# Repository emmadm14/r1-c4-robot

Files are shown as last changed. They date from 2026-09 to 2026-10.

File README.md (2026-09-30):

# R1-C4 – Experimental Assistant Robot

<p align="center">
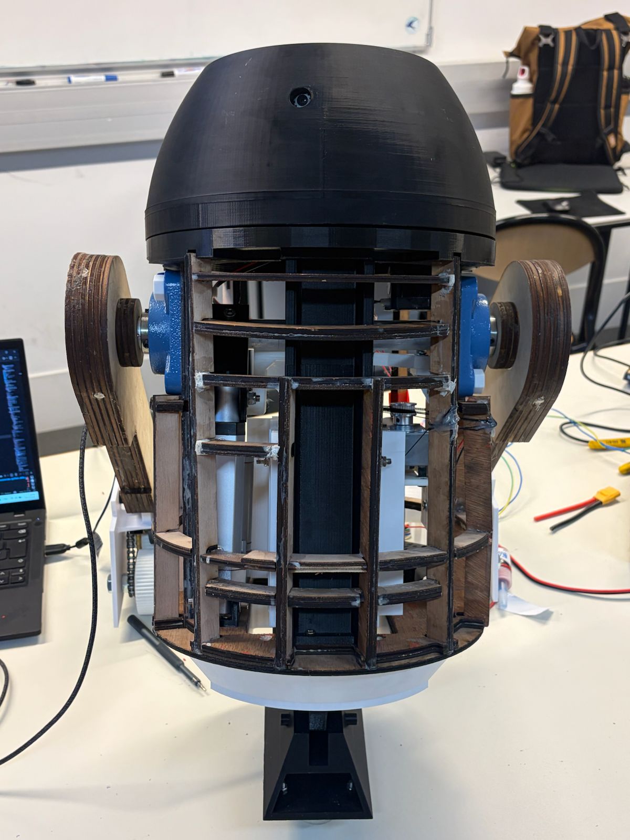
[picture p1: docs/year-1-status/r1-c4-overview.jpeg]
R1-C4 robot prototype
  
</p>

R1-C4 is an experimental assistant robot project inspired by the R2-D2 universe and developed at **Polytech Nice Sophia** as part of the **Experimental Robotics** course.

The project can be developed throughout the three years of the engineering cycle. I am currently in the **second year of development** of R1-C4.

The objective is to progressively design, prototype and improve a functional assistant robot at approximately **3/5 scale**, combining mechanical design, embedded systems, 3D printing, electronics, actuation and autonomous functions.

---

## Contents

- [Project Context](#project-context)
- [Project Objectives](#project-objectives)
- [Development History](#development-history)
- [Main Subsystems](#main-subsystems)
- [Design and Manufacturing](#design-and-manufacturing)
- [Documentation](#documentation)
- [Project Structure](#project-structure)
- [Technologies](#technologies)
- [Current Development](#current-development)
- [Authorship and Credits](#authorship-and-credits)

---

## Project Context

R1-C4 was started during my **3rd year of engineering studies** at Polytech Nice Sophia.

During the first development year, I worked on the project together with **Vladimir Grigoriev**.

My work focused mainly on:

- The **2-3-2 transformation system**
- The **central-foot lift**
- Mechanical integration
- Project cost assessment
- Global operating logic and documentation

Vladimir mainly worked on:

- The **wheel system**
- The **head / turret system**
- The first facial-recognition and tracking implementation

During my **4th year**, Vladimir moved to another robotics project and I decided to continue the development of R1-C4 independently.

The project is therefore now entering a new development phase focused on redesigning, improving and integrating the different subsystems into a more robust and complete robot.

---

## Project Objectives

The main objective of R1-C4 is to develop a semi-autonomous assistant robot inspired by the architecture and motion of R2-D2.

The project explores several engineering areas:

- Mechanical design and CAD
- Embedded electronics
- Robotics integration
- Actuator control
- Computer vision
- 3D printing
- Experimental prototyping
- System-level design

The robot is designed at approximately **3/5 scale**.

Reference dimensions from the **R2 Builders community** were used as a basis for defining the overall proportions of the robot before adapting them to the selected scale and project constraints.

---

## Development History

### First Development Year

The first year focused on validating the main mechanical and functional principles of the robot.

A first prototype was built using a wooden chassis inspired by existing R2-D2 construction approaches.

This phase made it possible to develop and test:

- A functional 2-3-2 body inclination mechanism
- A first central-foot lift
- An initial wheel system
- A rotating head
- Facial recognition and user tracking
- Initial embedded-electronics integration

The first prototype provided an important proof of concept but also highlighted several limitations related to rigidity, precision, compactness and mechanical reliability.

More information is available in:

[**End of Year 1 – Project Status**](docs/year-1-status/)

### Second Development Year

The second year focuses on redesigning and improving the robot based on the limitations identified during the first prototype phase.

Current work includes:

- Redesign and manufacturing of the new chassis
- Redesign of the central-foot lift
- Refinement of the 2-3-2 system
- Complete redesign of the wheel system
- Reorganisation of the electronics
- Adaptation of the facial-recognition system
- Improved integration of the different subsystems

---

## Main Subsystems

### 2-3-2 Transformation System

The 2-3-2 mechanism controls the inclination of the robot body and allows R1-C4 to transition between an upright configuration and a three-wheel driving configuration.

The system uses a linear actuator and lever mechanism to control body inclination.

[**Explore the 2-3-2 system →**](2-3-2-system/)

---

### Central-Foot Lift

The central-foot lift vertically deploys and retracts the robot's central foot.

The current redesign uses linear guidance, reinforced structural parts and a more compact architecture to improve mechanical stability.

The central foot is also equipped with ball-transfer units, allowing it to roll freely while the robot moves.

[**Explore the central-foot lift →**](central-foot-lift/)

---

### Chassis

The first chassis was manufactured in wood and used as a functional prototype.

After identifying limitations in rigidity, dimensional accuracy and ease of modification, the chassis was completely redesigned in CAD and manufactured by FDM 3D printing using PETG.

The new modular chassis is divided into several sections to simplify manufacturing, maintenance and future modifications.

[**Explore the chassis →**](chassis/)

---

### Wheel System

The first wheel system was developed during the first development year and was mainly designed by **Vladimir Grigoriev**.

Although it enabled initial driving tests, the mechanism progressively became unreliable and ultimately required a complete redesign.

The complete wheel architecture is therefore being redesigned during the second development year.

[**Explore the wheel system →**](wheel-system/)

---

### Head and Turret

The head/turret system combines facial recognition, target tracking and independent head rotation.

The first version included:

- LBPH facial recognition
- CSRT tracking
- Kalman filtering
- Stepper-motor-controlled head rotation

The first implementation was mainly developed by **Vladimir Grigoriev**.

Current work focuses on reorganising the electronics and adapting the facial-recognition system for continued development.

[**Explore the head and turret system →**](head-turret/)

---

## Design and Manufacturing

The project follows an iterative prototyping methodology:

1. Research existing solutions
2. Develop an initial concept
3. Build and test a functional prototype
4. Identify mechanical and integration limitations
5. Redesign the subsystem
6. Manufacture and test the improved version

Mechanical parts are designed primarily using **Fusion 360**.

Many structural components are manufactured by FDM 3D printing using **PETG** on:

- Prusa MK4
- Prusa XL

Printing parameters are adapted according to the mechanical role and geometry of each component.

---

## Documentation

The `docs/` folder contains the general engineering documentation associated with the project.

It includes:

- [Preliminary Research](docs/preliminary-research/)
- [End of Year 1 – Project Status](docs/year-1-status/)
- [Project Cost Assessment](docs/cost-assessment/)
- [Global Operating Algorithm](docs/operating-algorithm/)
- [Electronic Architecture](docs/electronic-architecture/)

---

## Project Structure

The repository is organised by subsystem and development area in order to clearly document the evolution of R1-C4.

```text
r1-c4-robot/
├── README.md
├── docs/
│   ├── preliminary-research/
│   ├── year-1-status/
│   ├── cost-assessment/
│   ├── operating-algorithm/
│   └── electronic-architecture/
├── 2-3-2-system/
│   ├── mechanical/
│   │   └── cad-parts/
│   ├── images/
│   │   ├── first-development-phase/
│   │   └── second-development-phase/
│   └── videos/
│       └── second-development-phase/
├── central-foot-lift/
│   ├── mechanical/
│   │   ├── assembly/
│   │   ├── cad-parts/
│   │   └── cad-animation/
│   ├── images/
│   │   └── first-development-phase/
│   └── videos/
│       └── first-development-phase/
├── chassis/
│   ├── mechanical/
│   │   ├── assembly/
│   │   └── cad-parts/
│   └── images/
│       └── first-development-phase/
├── wheel-system/
│   └── previous-version/
│       ├── images/
│       └── videos/
└── head-turret/
    └── videos/
        └── first-development-phase/
```

---

## Technologies

- Fusion 360
- CAD modelling
- C / C++
- ESP32
- Jetson Nano
- Embedded systems
- Computer vision
- OpenCV
- 3D printing
- PETG
- Mechanical design
- Actuator control
- Sensor and system integration
- Experimental robotics

---

## Current Development

R1-C4 is still an active project.

Current priorities include:

- Completing the new chassis integration
- Finalising the redesigned central-foot lift
- Redesigning the wheel system
- Reorganising the electronics
- Improving system reliability
- Continuing vision and tracking development
- Preparing the robot for controlled movement
- Progressively introducing more autonomous behaviours

The repository will evolve alongside the physical robot as new components are designed, manufactured and tested.

---

## Authorship and Credits

The first development year of R1-C4 was carried out in collaboration with **Vladimir Grigoriev**.

His contributions are identified in the relevant sections of this repository.

Unless otherwise stated, the **CAD models, images, videos, documentation and other resources shared in this repository are my own work**.

---

## Author

**E. Da Mota**  
Engineering student – Autonomous Robotics  
Polytech Nice Sophia – Université Côte d’Azur

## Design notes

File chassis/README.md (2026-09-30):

# Chassis

The chassis is the main structural element of R1-C4 and provides the mechanical support required to integrate the robot's different subsystems.

Its design evolved significantly throughout the project, from an initial wooden prototype to a fully redesigned PETG structure intended to improve rigidity, precision, modularity and ease of manufacturing.

## Design References and Scaling

The initial dimensions of R1-C4 were defined using reference measurements from the R2 Builders community.

These dimensions were adapted to the approximately 3/5 scale selected for the project in order to preserve the general proportions of an R2-D2-inspired robot while remaining compatible with the available manufacturing resources and internal components.

The first chassis was based on wooden construction plans inspired by Mike Senna's R2-D2 designs.

These references provided a useful starting point for establishing the overall geometry and internal organisation of the robot.

## Wooden Prototype

The first chassis was manufactured in wood and used during the initial development phase.

This structure made it possible to validate:

- The general dimensions of the robot
- The integration of the first mechanical subsystems
- The 2-3-2 transformation mechanism
- The first central-foot lift system
- The available internal space for electronics and actuators

Although functional as a prototype, the wooden chassis presented several limitations.

In particular, the structure lacked sufficient dimensional precision and mechanical rigidity for the more advanced stages of the project.

Its construction also made modifications and part replacement more difficult.

These limitations motivated a complete redesign of the chassis.

## PETG Chassis Redesign

The new chassis was fully redesigned in CAD and manufactured using PETG through FDM 3D printing.

The objective was to obtain a structure that was:

- More rigid
- More dimensionally accurate
- Easier to reproduce
- Easier to modify
- Better suited for integrating the different mechanical systems
- More modular for future development

Two main CAD approaches were explored:

- A complete one-piece chassis model
- A modular version divided into several printable sections

The modular version was selected to make manufacturing easier and to allow individual sections to be modified or replaced without reprinting the entire chassis.

## Modular Architecture

The final chassis design is divided into five main sections.

These parts are assembled together to form the complete structure while preserving the overall geometry of the robot.

This modular approach provides several advantages:

- Reduced risk of large-print failure
- Easier manufacturing on available printers
- Easier replacement of damaged parts
- Greater flexibility for future modifications
- Reduced material waste when only one section requires redesign

The complete assembled chassis is available in the `mechanical/assembly/` folder, while the five individual sections are provided in `mechanical/cad-parts/`.

## Manufacturing

The structural chassis parts are manufactured in PETG using Prusa MK4 and Prusa XL 3D printers.

The printer is selected according to the dimensions of each component.

For the main structural parts, reinforced printing parameters were used to improve stiffness and mechanical strength, including:

- 6 perimeters
- 40% gyroid infill
- Reinforced top and bottom layers

The printing parameters were adapted depending on the geometry and mechanical role of each section.

This manufacturing strategy was selected to provide a stronger and more reliable structure than the initial wooden prototype.

## Images

The `images/` folder documents the evolution of the chassis.

It currently includes photographs of the original wooden prototype used during the first development phase.

Additional images of the redesigned PETG chassis will be added as manufacturing and assembly progress.

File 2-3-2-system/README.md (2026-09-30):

# 2-3-2 Transformation System

The 2-3-2 transformation system is one of the main mechanical subsystems of R1-C4.

Its purpose is to allow the robot to transition between an upright two-leg configuration and a three-wheel configuration by controlling the inclination of the body and coordinating this movement with the deployment of the central foot.

## System Principle

The transformation is based on two complementary mechanical functions:

- Tilting the robot body using a linear actuator and lever mechanism
- Deploying the central foot through the dedicated lift system

During the transition, the body progressively tilts while the central foot moves into position, allowing the robot to adopt a more stable three-wheel configuration for movement.

The 2-3-2 mechanism therefore plays an important role in both the posture and mobility of R1-C4.

## Mechanical Design

The body inclination mechanism uses a linear actuator connected to a lever arm.

The motion of the actuator is converted into a controlled rotation of the robot body, allowing it to move between its upright and inclined positions.

The design had to take into account several constraints:

- Available space inside the chassis
- Required inclination angle (32°)
- Load distribution
- Mechanical stability
- Integration with the central-foot lift system
- Strength of the supporting parts

## Development

The first version of the 2-3-2 mechanism was developed during the first year of the project and validated as part of the initial R1-C4 prototype.

During the second development year, the system is being refined to improve its mechanical integration, reliability and compatibility with the redesigned chassis and central-foot lift.

The current design uses a dedicated linear actuator support and lever arm to control the inclination of the robot body.

## CAD Files

The `mechanical/cad-parts/` folder contains the individual CAD parts designed for the 2-3-2 system.

These files include components such as:

- Linear actuator mount
- Linear actuator lever arm

The CAD models are provided in STEP format to allow easy visualisation, modification and reuse in different CAD software.

## Future Assembly Model

A complete CAD assembly of the 2-3-2 mechanism will be added once the current version of the system has been fully integrated with the linear actuator and surrounding mechanical components.

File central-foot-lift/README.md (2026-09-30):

# Central-Foot Lift System

The central-foot lift is one of the main mechanical subsystems of R1-C4 and plays an essential role in the 2-3-2 transformation.

Its purpose is to vertically deploy and retract the central foot, allowing the robot to transition between its upright configuration and its three-wheel driving configuration.

## System Principle

The lift mechanism moves the central foot vertically inside the robot chassis.

During the transition to the three-wheel configuration, the central foot is lowered until it reaches the ground. When the robot returns to its upright configuration, the foot is retracted inside the body.

The system therefore had to provide:

- Controlled vertical motion
- Sufficient mechanical stability
- Compact integration inside the chassis
- Reliable guidance of the moving assembly
- Support for the loads transmitted through the central foot

## First Development Phase

The first functional version of the lift used a belt-driven transmission to generate the vertical movement of the central foot.

This prototype successfully demonstrated that the foot could be extended and retracted in both directions.

However, testing also highlighted several limitations.

The initial guiding solution had been adapted to reduce the space occupied inside the robot, but this resulted in insufficient mechanical stability.

The mechanism was also relatively bulky compared with the available space inside R1-C4.

These observations led to a complete redesign of the central-foot lift.

Images and demonstration videos of this first functional prototype are available in the corresponding development folders.

## Redesigned Lift System

The redesigned system was developed to improve compactness, guidance and mechanical stability.

The current architecture uses two linear guides to control the vertical motion of the lift carriage and reduce unwanted movement.

The central foot is attached to this moving carriage, which travels vertically inside the chassis.

The redesign also required the development of several dedicated mechanical components, including:

- Central-foot lift carriage
- Front linear-guide assembly
- Rear linear-guide assembly
- Lift motor mounting bracket
- Linear-motion stop
- Central foot
- Structural supports and interfaces

## Mechanical Design Choices

Several parts of the redesigned lift were reinforced using ribs.

The objective was to increase stiffness and resistance to deformation in mechanically loaded areas while avoiding unnecessary material and mass.

This approach was particularly useful for the 3D-printed structural components supporting the lift and guiding systems.

The geometry of the different parts was also designed to remain compact enough for integration within the limited internal volume of R1-C4.

## Central-Foot Mobility

The central foot is equipped with flanged-mount ball transfer units underneath its base.

These allow the foot to remain in contact with the ground while rolling freely as the robot moves in its three-wheel configuration.

This provides multidirectional ground support without requiring a dedicated steering mechanism for the central foot.

## CAD Assembly

The complete lift mechanism was modelled in Fusion 360.

Mechanical joints were added to the assembly to reproduce the vertical movement of the central foot and verify the motion of the mechanism before physical integration.

Two STEP assemblies are provided to represent the extreme positions of the system:

- `R1-C4 - Central-foot-assembly-retracted.step`
- `R1-C4 - Central-foot-assembly-extended.step`

The STEP files contain the mechanical geometry of the system, while the CAD animation demonstrates the continuous motion between these two positions.

The motor mounting bracket is included in the assembly, although the motor itself is not represented in the CAD model.

## CAD Files

The `mechanical/cad-parts/` folder contains the individual components designed for the redesigned central-foot lift.

The CAD models are provided in STEP format to allow easy visualisation and compatibility with different CAD software.

## CAD Animations

The `mechanical/cad-animation/` folder contains animations generated from the Fusion 360 assembly.

These animations show:

- The vertical motion of the central-foot lift
- The integration of the mechanism within the robot chassis

They complement the STEP models by illustrating the actual kinematic behaviour of the assembly.

## Prototype Tests

Videos of the first development phase demonstrate the extension and retraction of the original central-foot mechanism.

These tests confirmed the operating principle of the lift before the system was redesigned to improve its compactness and mechanical stability.

## Manufacturing

The structural components of the redesigned lift are manufactured primarily using FDM 3D printing in PETG.

The parts are produced using Prusa MK4 and Prusa XL printers depending on their dimensions.

Specific printing parameters are adapted according to the geometry and mechanical function of each component.

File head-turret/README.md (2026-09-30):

# Head and Turret System

The head and turret system is responsible for the visual interaction and orientation functions of R1-C4.

During the first development year, the rotating head, facial recognition and user-tracking functions were developed and integrated into the prototype.

The mechanical design of the head and most of the initial vision and tracking implementation were mainly developed by **Vladimir Grigoriev**.

## System Principle

The objective of the system is to allow R1-C4 to detect and recognise a user, then rotate its head in order to follow the user's movement.

The system combines:

- Camera-based user detection
- Facial recognition
- Real-time target tracking
- Head rotation control

The vision processing is handled by the main computing platform, while correction commands are sent to the embedded controller responsible for actuating the turret.

## Vision and Tracking

The first version of the vision system included:

- LBPH facial recognition
- CSRT real-time tracking
- Kalman filtering for motion prediction

Once a user is detected and recognised, the tracking algorithm follows their movement and generates correction commands to orient the head.

## Head Rotation

The turret is driven by a stepper motor controlled through a TMC2209 driver.

This allows the head to rotate independently from the robot body and follow the detected user.

## First Development Phase

During the first development year, the system was successfully tested with facial recognition and head tracking.

The available demonstration video shows the robot recognising **Vladimir Grigoriev** and rotating the head in order to follow his movement.

This first implementation validated the general principle of the vision and turret-control system.

## Current Development

During the second development year, the existing head architecture is being retained while several elements are being updated.

The current work includes:

- Reorganising the electronics inside the head
- Adapting the facial-recognition data for a new user
- Improving the integration of the vision system with the rest of the robot
- Preparing the head system for future autonomous behaviours

The mechanical geometry of the head itself is not being redesigned as part of the current development work.

## Documentation

The `videos/` folder contains demonstrations of the first facial-recognition and head-tracking implementation.

Additional software and electronics documentation will be added as the head/turret system continues to evolve.

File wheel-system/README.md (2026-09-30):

# Wheel System

The wheel system provides the main propulsion of R1-C4 when the robot is operating in its three-wheel configuration.

The system has evolved significantly throughout the project.

## Previous Version

During the first development year, an initial wheel system was developed and integrated into the prototype.

The mechanical design of this first version was mainly carried out by **Vladimir Grigoriev**.

Although the system was functional during early testing, its performance was not sufficiently smooth or reliable, and the mechanism eventually failed.

This highlighted the need for a complete redesign of the propulsion system.

Documentation of this first version is available in:

- `previous-version/`

## Current Redesign

During the second development year, the wheel system is being completely redesigned.

The objective of the new version is to improve:

- Reliability
- Mechanical robustness
- Driving performance
- Integration with the new PETG chassis
- Compatibility with the updated mechanical architecture of R1-C4

The redesign is currently in progress and will be documented in this repository as development continues.

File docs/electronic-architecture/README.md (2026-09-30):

# Electronic Architecture

This diagram presents the overall electronic architecture developed for R1-C4 during the first development year.

The objective was to define how the main computing, control, power and actuation components would be interconnected within the robot.

## Main Components

The architecture includes several key elements:

- **Jetson Nano** for high-level processing and vision-related tasks
- **ESP32** for embedded control and communication with the actuators
- **TMC2209 stepper motor driver** for head rotation
- **Dual DC motor driver** for the two main drive motors
- **Relay modules** for controlling the linear actuator
- **DC-DC buck converter** for voltage adaptation
- **Power supply** for the complete system
- **Linear actuator** for the 2-3-2 transformation mechanism
- **DC motors** for robot movement
- **Lift motor** for the central-foot lift system
- **Webcam** for visual input

## System Organisation

The Jetson Nano acts as the main computing platform for higher-level functions such as image processing and user tracking.

The ESP32 is used for lower-level control and interfaces with the motor drivers, relays and other actuators.

The power stage distributes the required voltages to the different components. A DC-DC converter is used to reduce the supply voltage for components requiring a lower operating voltage.

The relay modules are used to control the linear actuator, while dedicated motor drivers handle the different DC and stepper motors.

## Purpose of the Diagram

This architecture diagram was created to visualise the interactions between the main electronic components before full integration inside the robot.

It also helped organise the distribution of power, control signals and actuator connections within R1-C4.

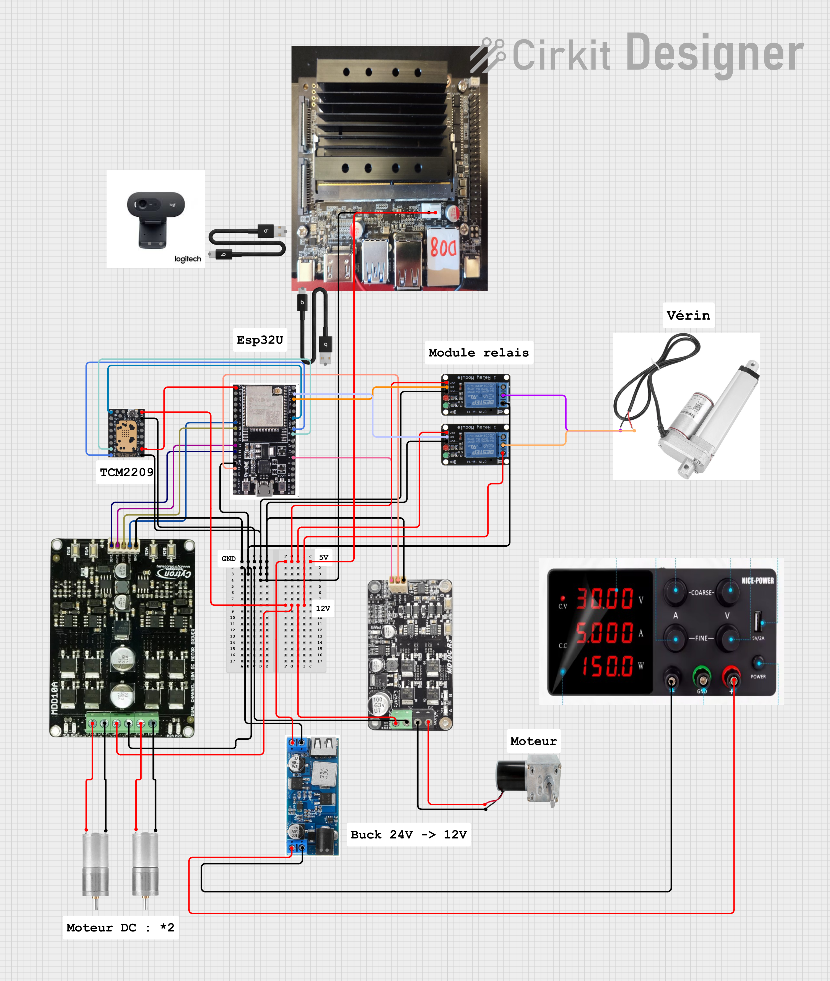
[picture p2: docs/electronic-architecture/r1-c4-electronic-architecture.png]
R1-C4 Electronic Architecture


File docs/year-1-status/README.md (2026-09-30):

# End of Year 1 – Project Status

At the end of the first development year, R1-C4 had reached the stage of a functional prototype.

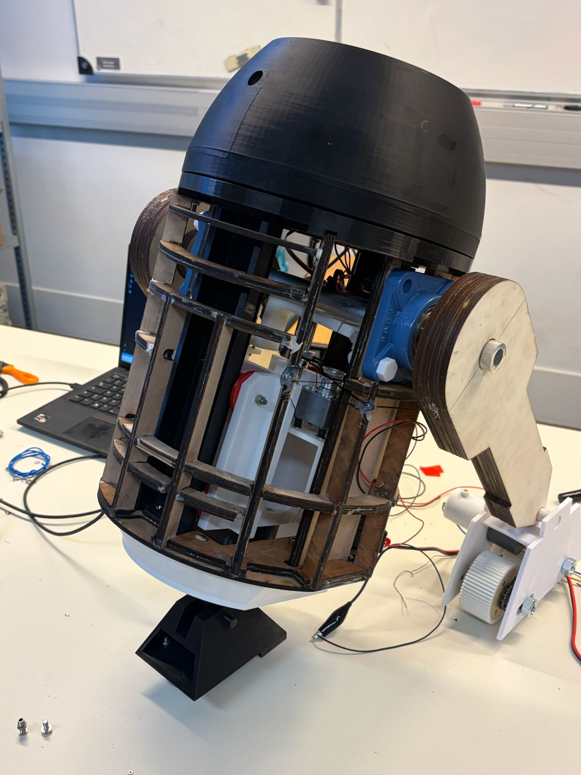
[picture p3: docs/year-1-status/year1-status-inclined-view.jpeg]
Year 1 prototype - inclined view


The first year focused mainly on the mechanical architecture of the robot, while also introducing the first elements of embedded electronics, vision and autonomous behaviour.

This stage made it possible to validate several key subsystems and identify the main technical limitations to address during the following development year.

## Functional Systems

By the end of the first year, the following elements had been implemented or validated:

- 2-3-2 transformation mechanism
- Central-foot lift system
- Rotating head/turret
- Initial facial recognition and tracking functions
- Preliminary embedded electronics architecture

## Mechanical Development

A major part of the first development year focused on the mechanical design of R1-C4.

The **2-3-2 transformation mechanism** was developed to allow the robot to transition between a two-leg configuration and a three-wheel configuration by controlling the inclination of the body.

The **central-foot lift system** was developed as part of this transformation process, allowing the central foot to move in and out of the robot's body.

Several mechanical and structural components were designed for 3D printing, while the main chassis was still based on the original wooden prototype.

Because of the relatively large dimensions of R1-C4 and the limitations of the available printers, some large components had to be divided into several smaller parts. This reduced the risk of failed prints and made future modifications easier.

## Electronics and Control

A first embedded-electronics architecture was defined during the first year.

The system included:

- Jetson Nano for image processing and artificial intelligence
- ESP32 for central control
- Motor drivers for the different actuators
- Stepper-motor control for the head/turret
- Power conversion and distribution components

The electronic architecture was designed to remain modular and accessible in order to simplify wiring, maintenance and future integration.

## Vision and Tracking

The first version of the vision system combined:

- LBPH for facial recognition
- CSRT for real-time target tracking
- Kalman filtering for trajectory prediction

The objective was to allow the robot to recognise a user, follow their movement and send correction commands to the ESP32 in order to control the head/turret.

## Project Assessment

The first development year also included:

- A complete cost assessment of the robot
- A global operating algorithm
- A review of the initial design choices
- Identification of the main technical limitations
- Definition of the priorities for the second development year

More detailed information is available in the dedicated documentation:

- [Cost Assessment](../cost-assessment/)
- [Operating Algorithm](../operating-algorithm/)

## Lessons Learned

The first year highlighted several important design limitations.

One of the main issues concerned the central-foot lift system.

In order to save space inside the robot, the initial guiding solution was adapted with fewer contact points. This reduced the stability of the mechanism and showed that the original concept had not been sufficiently adapted to the scale and internal constraints of R1-C4.

This led to the decision to redesign the lift system during the following development year.

Another major challenge concerned the size of the structural parts. Large 3D prints were time-consuming and carried a significant risk of failure, which encouraged a more modular design approach.

## Remaining Limitations

At the end of the first year, several areas still required further development:

- The wheel system was not yet sufficiently optimised for smooth and reliable movement.
- Stability in the two-leg configuration still required improvement.
- The central-foot lift system needed to be redesigned for greater stability and compactness.
- The electronic integration still required further organisation.
- The overall appearance of the robot still reflected its prototype stage.
- Further autonomous functions remained to be developed.

## Transition to Year 2

The second development year focuses on improving the reliability, modularity and integration of R1-C4.

The main priorities include:

- Redesigning the central-foot lift system
- Redesigning the chassis
- Improving the modularity of the mechanical structure
- Redesigning the wheel system
- Improving electronic integration
- Preparing the robot for reliable movement
- Continuing the development of autonomous functions

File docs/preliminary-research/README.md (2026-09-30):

# Preliminary Research

Before starting the design of R1-C4, a preliminary research phase was carried out to study existing robotic solutions and define the most suitable architecture for the project.

The objective was to avoid starting the mechanical design without first analysing the main technical constraints and comparing several possible approaches.

The research focused on the main subsystems of the robot:

- Wheel and drive systems
- 2-3-2 transformation mechanism
- Central retractable foot
- Rotating head/turret
- Motorisation and actuator selection
- Mechanical stability and integration constraints

Several existing R2-D2-inspired robots, prototypes and mechanisms were analysed in order to understand their advantages, limitations and suitability for a robot built at approximately 3/5 scale.

This preliminary study helped guide the first design choices and provided a technical basis for the initial development of R1-C4.

## Main Design Considerations

The research phase highlighted several key requirements:

- The robot had to remain stable during the transition between two-wheel and three-wheel configurations.
- The 2-3-2 mechanism had to control the inclination of the body within a defined angle.
- The central foot had to move vertically while remaining aligned and stable.
- The wheel system had to provide sufficient torque while remaining compact.
- The head had to rotate independently from the body.
- The overall architecture had to remain modular and accessible for maintenance.

The conclusions from this research were then used to define the first version of the mechanical architecture and select the main components for the prototype.

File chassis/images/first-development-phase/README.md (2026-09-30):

# Wooden Prototype Chassis

This folder contains photographs of the initial wooden chassis used during the first development phase of R1-C4.

The structure was based on an existing wooden R2-D2-inspired design and adapted to the approximately 3/5 scale selected for the project.

This first chassis provided a practical framework for:

- Validating the overall dimensions of the robot
- Integrating the first mechanical subsystems
- Testing the 2-3-2 transformation mechanism
- Installing the first version of the central-foot lift
- Evaluating the available internal space

Although functional as a prototype, the wooden structure presented several limitations in terms of precision, rigidity and reproducibility.

These limitations motivated the transition toward a redesigned PETG chassis with improved structural strength, dimensional accuracy and modularity.

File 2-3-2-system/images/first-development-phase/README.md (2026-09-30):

# First Development Phase

This folder contains photographs of the first functional version of the R1-C4 2-3-2 transformation system.

During this development phase, the objective was to validate the mechanical principle of the body inclination mechanism before redesigning the system for improved compactness and integration.

## Prototype Configuration

The first prototype included:

- A linear actuator used to control the body inclination
- A lever mechanism connecting the actuator to the main body axis
- The main rotation shaft and bearing supports
- Integration of the mechanism within the original wooden chassis
- Preliminary electronic control components used during testing

## Purpose of This Version

This configuration made it possible to validate the basic operation of the 2-3-2 transformation mechanism and confirm that the robot body could be tilted using the linear actuator.

Although functional, the first version also highlighted several limitations related to sturdiness and reliability.

These observations were later used to guide the redesign of the chassis and the mechanical systems during the second development phase.

## Images

The photographs in this folder show:

- An overview of the first 2-3-2 prototype
- The linear actuator and lever mechanism
- The integration of the inclination system within the original chassis

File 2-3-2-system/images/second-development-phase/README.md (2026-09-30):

# Second Development Phase

This folder contains photographs of the second development phase of the R1-C4 2-3-2 transformation system.

After validating the operating principle with the first prototype, the mechanism was progressively refined to improve its mechanical integration and overall quality.

## Mechanical Improvements

One of the main improvements during this phase was the replacement of several temporary wooden components used in the initial prototype.

The linear actuator mounting system was redesigned using dedicated 3D-printed parts, including:

- A 3D-printed linear actuator mount
- A 3D-printed lever arm
- Improved interfaces between the actuator and the body rotation mechanism

These components replaced the earlier wooden prototype parts and provided a cleaner, more reproducible and better integrated mechanical solution.

## Purpose of This Version

The objective of this phase was to move from a proof-of-concept mechanism toward a more refined prototype while preserving the transformation principle validated during the first development phase.

This version also provided experience that would later be used for the current redesign of the chassis and the 2-3-2 system.

## Image

The photograph in this folder shows the improved 2-3-2 mechanism integrated into the original chassis, with the redesigned linear actuator mount and lever arm.

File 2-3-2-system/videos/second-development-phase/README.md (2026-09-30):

# Second Development Phase – Demonstration Videos

This folder contains demonstration videos of the R1-C4 2-3-2 transformation system during the second development phase.

At this stage, the inclination mechanism had already evolved beyond the initial wooden prototype and incorporated improved mechanical components.

## Videos

- **Improved tilt and return test** – demonstration of the robot body tilting and returning to its upright position using the improved 2-3-2 mechanism.
- **Final tilt test** – demonstration of the refined inclination movement.
- **Final return-to-upright test** – demonstration of the mechanism returning the robot body to its upright position.

These videos illustrate the progressive improvement of the 2-3-2 system during the second development phase.

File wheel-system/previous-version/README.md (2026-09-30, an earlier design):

# Previous Wheel System

This folder documents the first version of the R1-C4 wheel system developed during the first year of the project.

The mechanical design of this version was mainly developed by **Vladimir Grigoriev**, with integration and testing carried out as part of the R1-C4 project.

## System Principle

The first wheel system used a motor-driven transmission integrated into the robot's side leg.

The mechanism included:

- A DC motor
- A chain transmission
- A driven wheel
- Structural support parts integrated into the leg
- Mechanical interfaces connecting the wheel system to the rest of the robot

This architecture made it possible to obtain an initial functional propulsion system for R1-C4.

## Testing and Limitations

The system was tested on the prototype and was able to drive the robot during the first development phase.

However, the performance was not sufficiently smooth or reliable for continued use.

During testing, the system progressively showed mechanical limitations and eventually became unusable.

This confirmed that the original architecture required a complete redesign in order to improve:

- Reliability
- Mechanical robustness
- Transmission efficiency
- Integration with the chassis
- Overall driving performance

## Documentation

The `images/` folder contains photographs of the previous wheel system and its integration into the prototype.

The `videos/` folder contains a driving test demonstrating the operation of the first version before the system failed.

This previous version is included to document the evolution of the project and provide context for the current redesign of the R1-C4 wheel system.

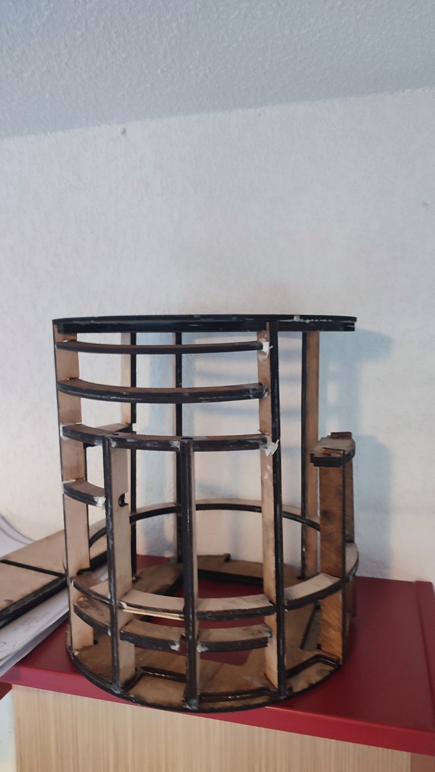
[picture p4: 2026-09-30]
chassis/images/first-development-phase/wooden-chassis-overview.jpeg

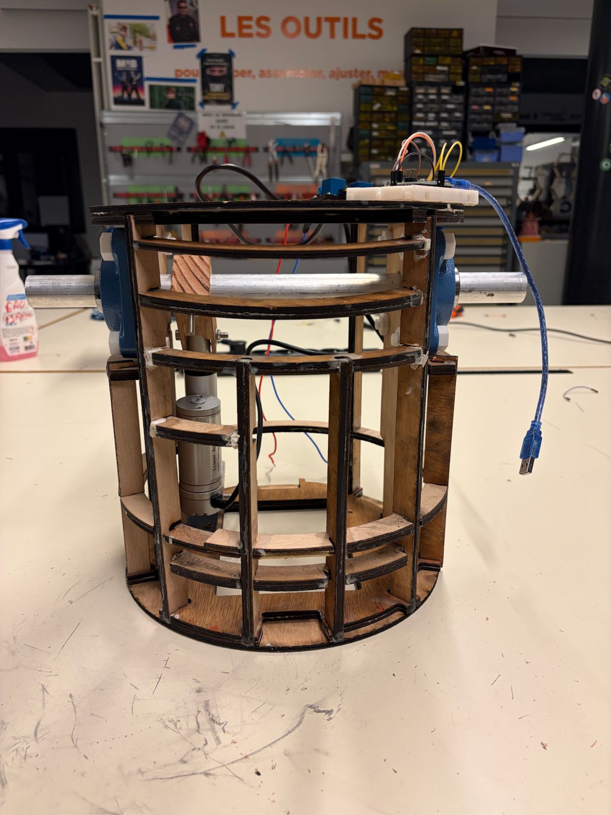
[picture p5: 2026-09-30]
2-3-2-system/images/first-development-phase/2-3-2-system-overview.jpeg

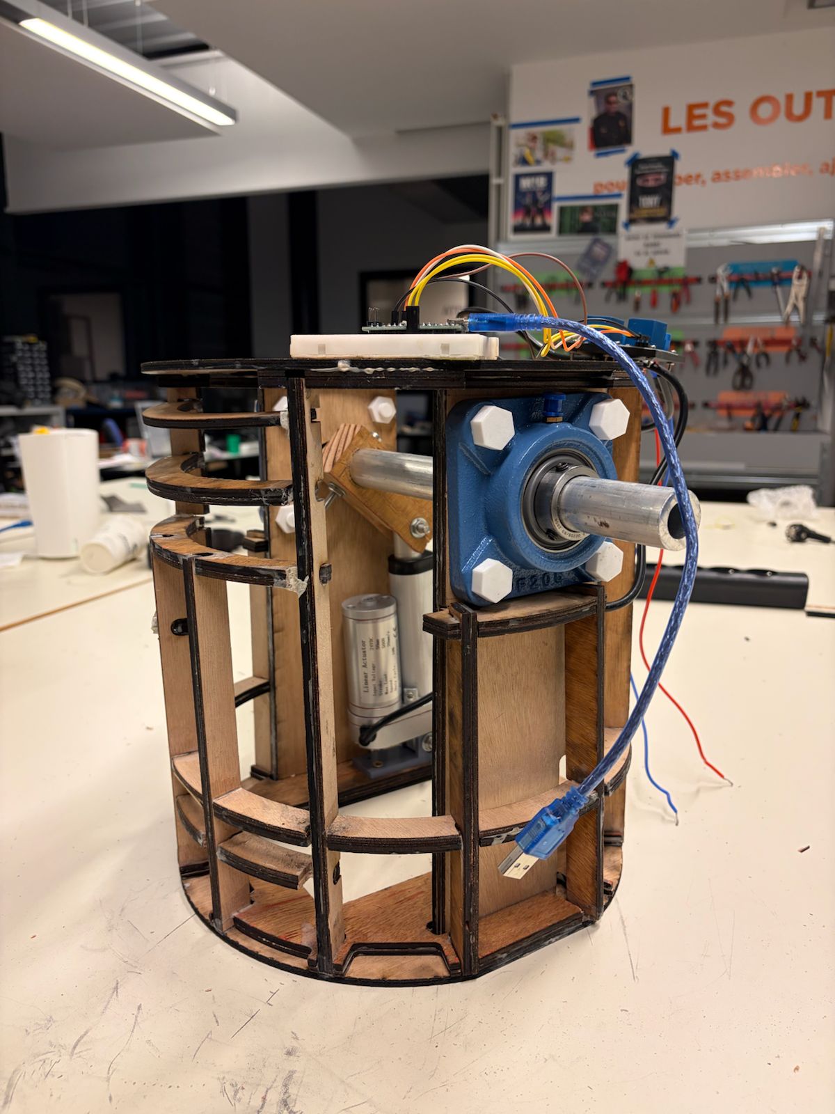
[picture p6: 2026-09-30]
2-3-2-system/images/first-development-phase/2-3-2-chassis-integration.jpeg

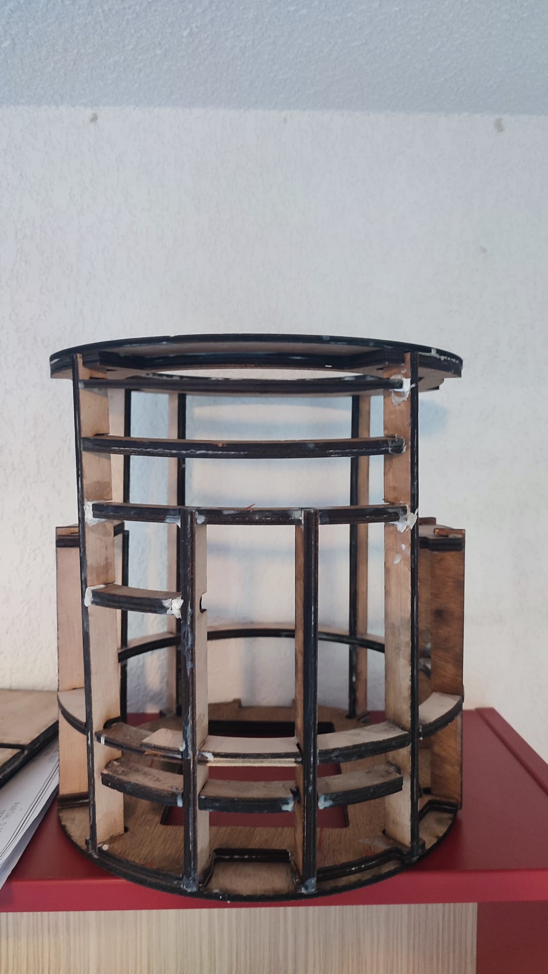
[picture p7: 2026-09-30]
chassis/images/first-development-phase/wooden-chassis-front-view.jpeg

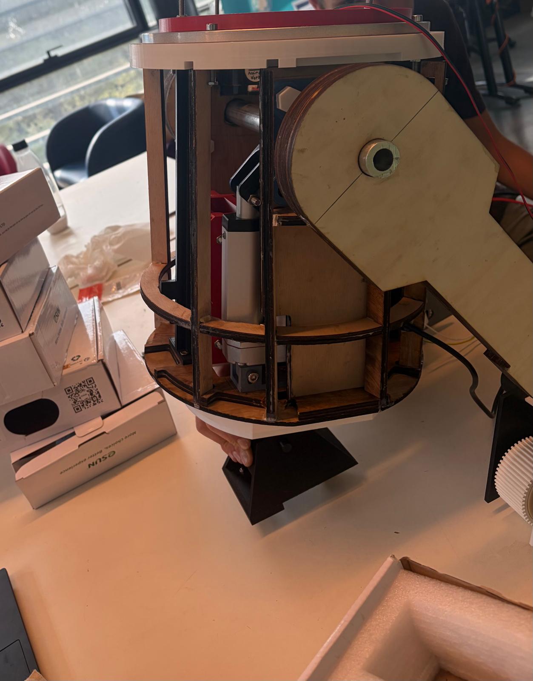
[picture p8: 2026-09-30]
2-3-2-system/images/second-development-phase/improved-2-3-2-mechanism.jpeg

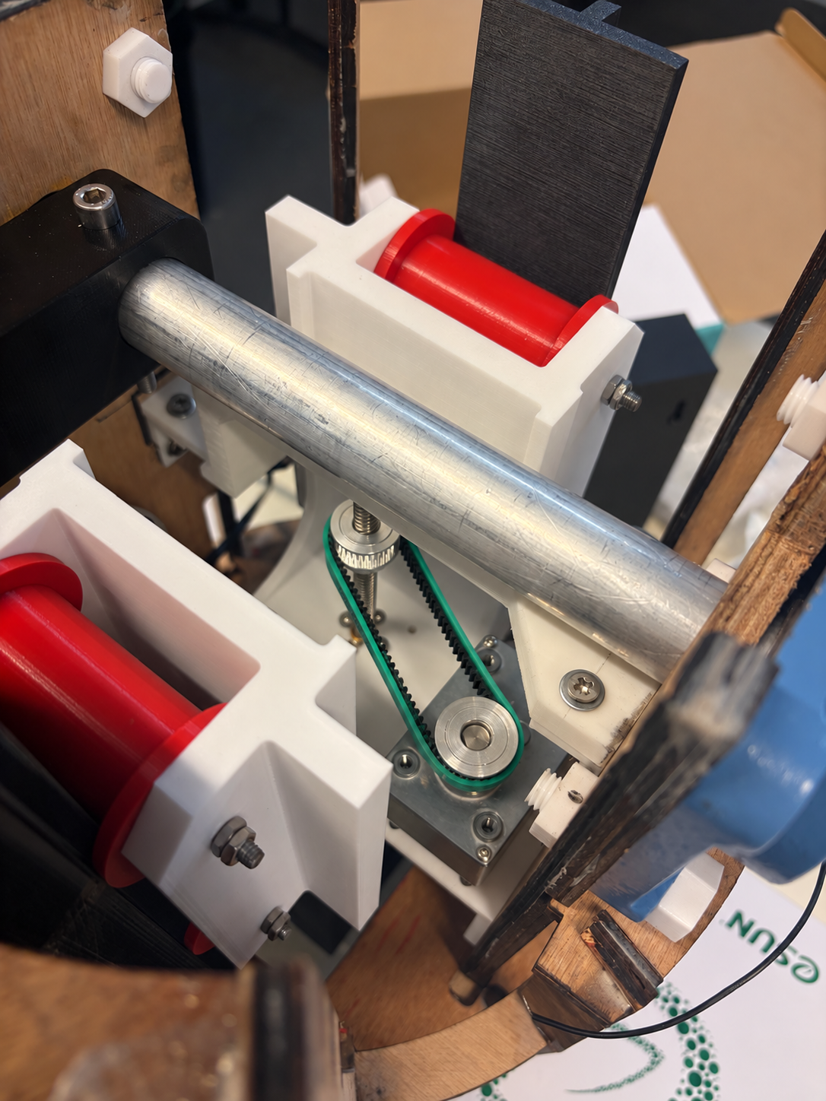
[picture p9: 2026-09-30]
central-foot-lift/images/first-development-phase/initial-lift-mechanism.png

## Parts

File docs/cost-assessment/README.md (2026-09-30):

# Project Cost Assessment

At the end of the first development year, a complete cost assessment was carried out to estimate the overall value of the R1-C4 project.

The analysis considered both the material cost of the prototype and the engineering time dedicated to its design, development, testing and documentation.

## Costing Method

The assessment was divided into two main categories:

- **Material cost**: based on the estimated purchase price and quantity of the components and materials required for the prototype.
- **Engineering cost**: based on the number of hours dedicated to the project.

An hourly engineering cost of **€23.75** was used for the calculation.

## Estimated Cost

The resulting estimates were:

- **Material cost:** €849.90
- **Engineering cost:** €9,690.00
- **Estimated total project cost:** €10,539.90

The engineering time included:

- **Emma:** 200 hours
- **Vladimir:** 208 hours

## Cost Distribution

The material assessment included the main components required for the prototype, such as:

- Embedded electronics and control components
- Motors and motor drivers
- Mechanical transmission components
- Linear actuator and bearings
- Structural materials
- 3D-printing material
- Fasteners and assembly hardware

## Purpose of the Assessment

This assessment provided a broader view of the R1-C4 project by taking into account not only the purchase price of the physical components, but also the engineering time required to develop the prototype.

It highlights the importance of design, prototyping, integration, testing and documentation in the overall cost of an engineering project.

The detailed calculations are available in the accompanying spreadsheet:

**`r1-c4-cost-assessment.xlsx`**

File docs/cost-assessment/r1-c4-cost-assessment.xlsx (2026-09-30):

Matériels | Prix (€) | Quantité (-) | Total (€) |  | Humain | Temps (h) | Coût horaire (€) | Total (€)
Module relais | 1 | 4 | 4 |  | Emma | 200 | 23.75 | 4750
Cytron Mdd10A | 30 | 1 | 30 |  | Vladimir | 208 | 23.75 | 4940
Cytron Mdd10C | 20 | 1 | 20
Esp32U | 5 | 1 | 5
Jetson nano | 250 | 1 | 250
Camera logitech | 20 | 1 | 20
Convertisseur Buck | 2 | 1 | 2
TMC2209 | 6 | 1 | 6
Roulement rotatif | 16 | 1 | 16
Vérin 500N - 50 mm | 30 | 1 | 30
Barre métallique 25 mm | 15 | 1 | 15
Roulement à paliers | 10.5 | 2 | 21
Roulements à billes | 0.89 | 10 | 8.9
Pignon distribution 8 mm | 3 | 2 | 6
Tige filetée 5 mm | 1.5 | 1 | 1.5
Tige filetée 8 mm - 25 mm | 8.5 | 1 | 8.5
Moteur DC - 27 rpm | 18 | 1 | 18
Tige linéaire 8 mm | 1 | 1 | 1
Chaine 25h | 8 | 1 | 8
Moteur DC série 919 | 27 | 2 | 54
PETG | 15 | 5 | 75
Contreplaqué - 3 mm | 20 | 4 | 80
Contrplaqué - 5 mm | 25 | 6 | 150
Visserie |  |  | 20
Coût matériel TOTAL = | 849.9 | € |  | Coût humain TOTAL = |  |  | 9690 | €
 | COÛT TOTAL R1-C4 = |  |  | 10539.9 | €

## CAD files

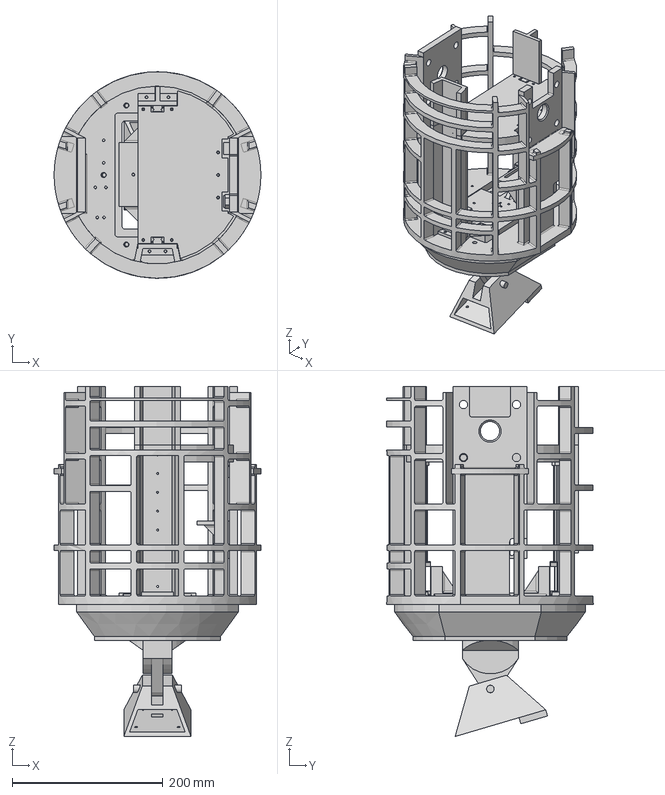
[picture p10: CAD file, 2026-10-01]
central-foot-lift/mechanical/assembly/R1-C4 - Central-foot-assembly-extended.step
274.3 x 274.3 x 464.7 mm
SZ12L_2 x 2

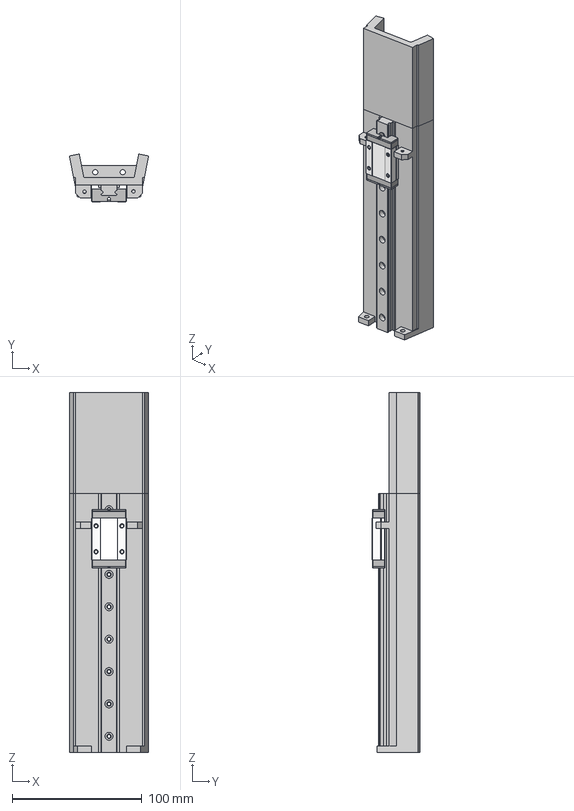
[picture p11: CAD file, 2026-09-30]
central-foot-lift/mechanical/cad-parts/R1-C4 - Front-linear-guide-assembly.step
61.2 x 37.0 x 278.0 mm
SZ12L_1

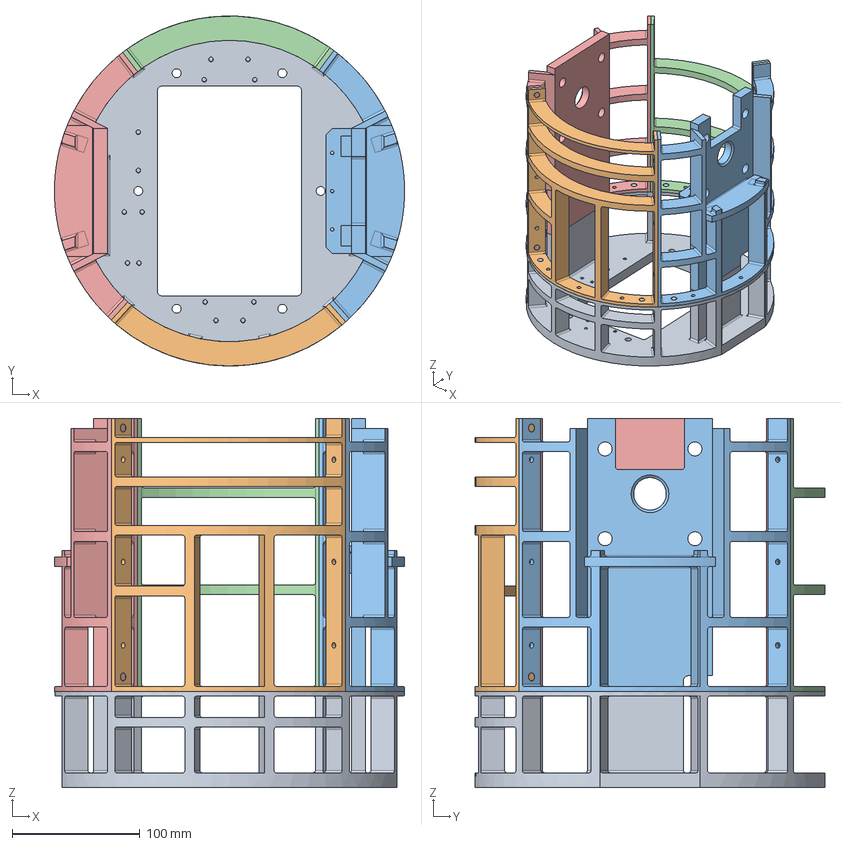
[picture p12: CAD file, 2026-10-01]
chassis/mechanical/assembly/R1-C4 - Chassis-assembly.step
274.5 x 274.3 x 289.3 mm

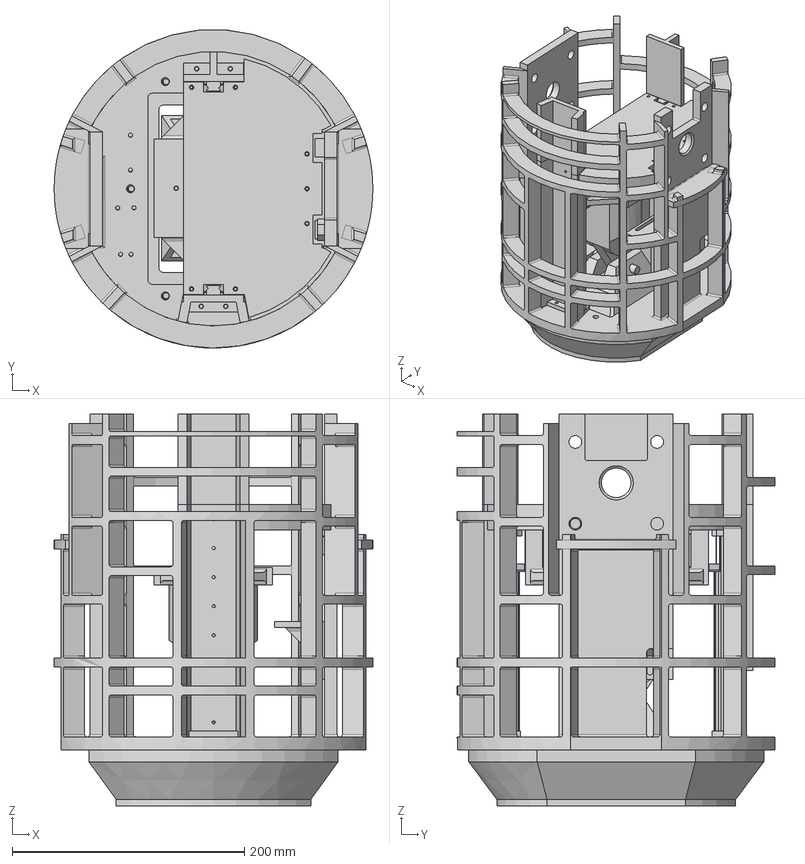
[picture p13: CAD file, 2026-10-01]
central-foot-lift/mechanical/assembly/R1-C4 - Central-foot-assembly-retracted.step
274.5 x 273.9 x 337.5 mm
SZ12L_2 x 2

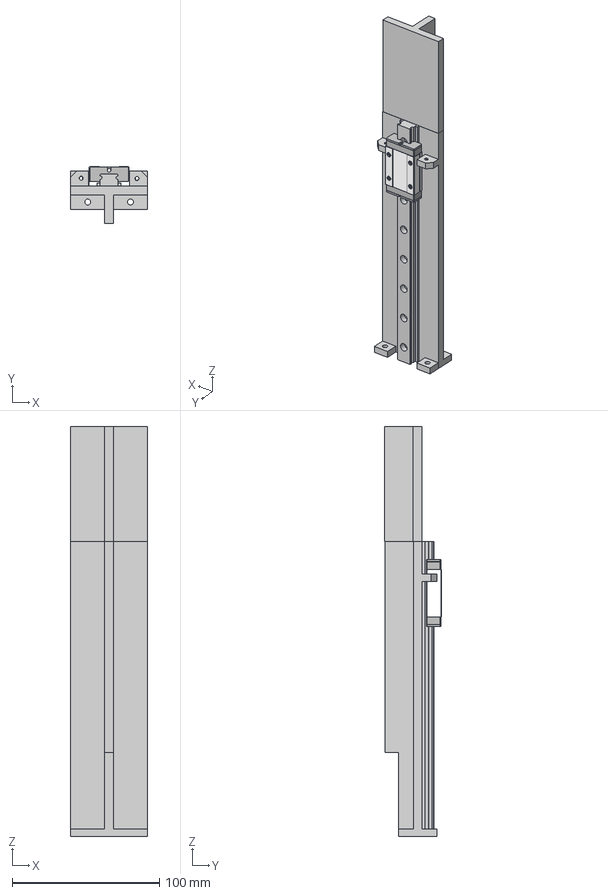
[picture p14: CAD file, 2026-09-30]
central-foot-lift/mechanical/cad-parts/R1-C4 - Rear-linear-guide-assembly.step
52.1 x 38.5 x 278.0 mm
SZ12L_1

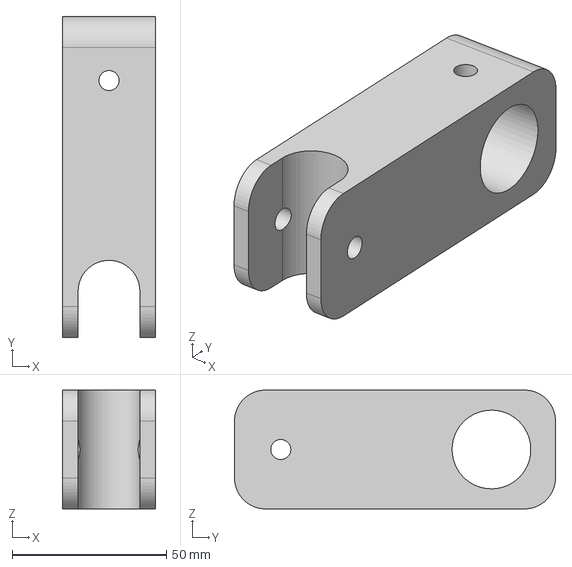
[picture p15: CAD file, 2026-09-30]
2-3-2-system/mechanical/cad-parts/R1-C4 - Linear actuator lever arm.step
30.0 x 104.0 x 38.5 mm

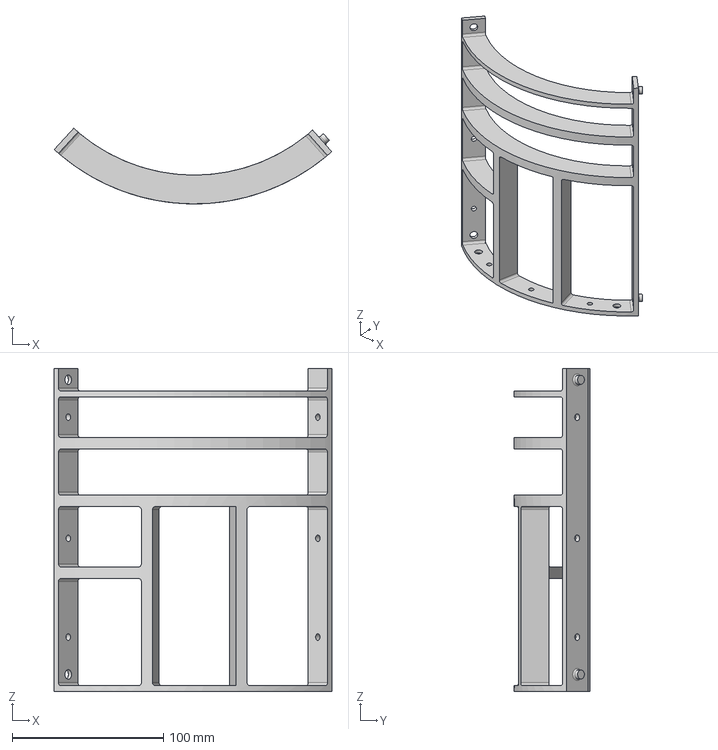
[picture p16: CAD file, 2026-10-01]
chassis/mechanical/cad-parts/R1-C4 - Chassis-part 2.step
183.7 x 50.2 x 213.8 mm

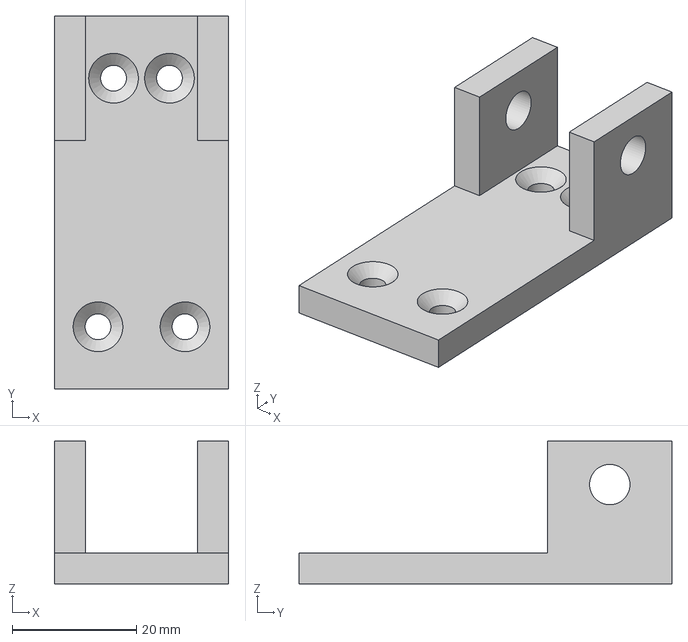
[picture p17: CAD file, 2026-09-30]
2-3-2-system/mechanical/cad-parts/R1-C4 - Linear actuator mount.step
28.0 x 60.0 x 23.0 mm

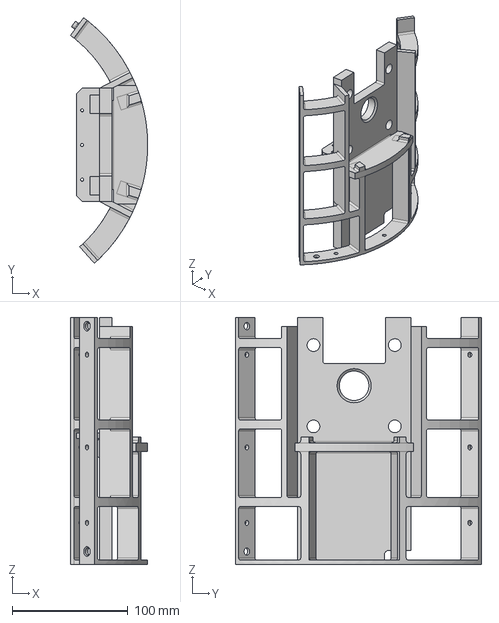
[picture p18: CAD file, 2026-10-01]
chassis/mechanical/cad-parts/R1-C4 - Chassis-part 3.step
66.9 x 212.7 x 213.8 mm

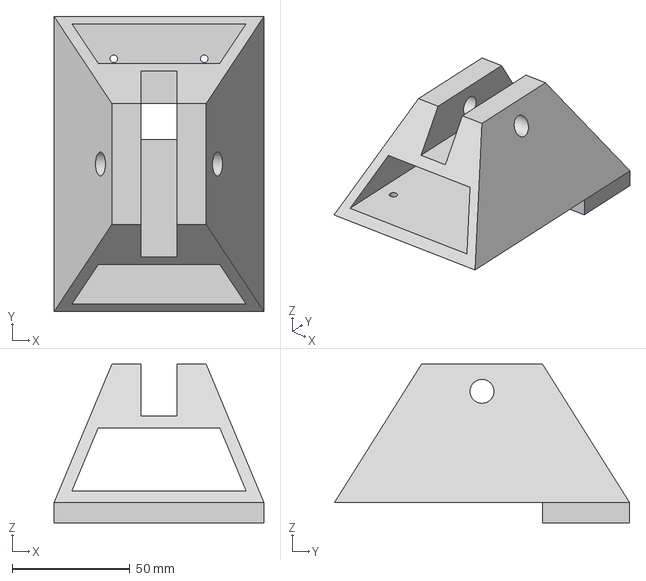
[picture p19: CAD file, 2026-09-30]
central-foot-lift/mechanical/cad-parts/R1-C4 - Central-foot.step
89.2 x 125.4 x 67.3 mm

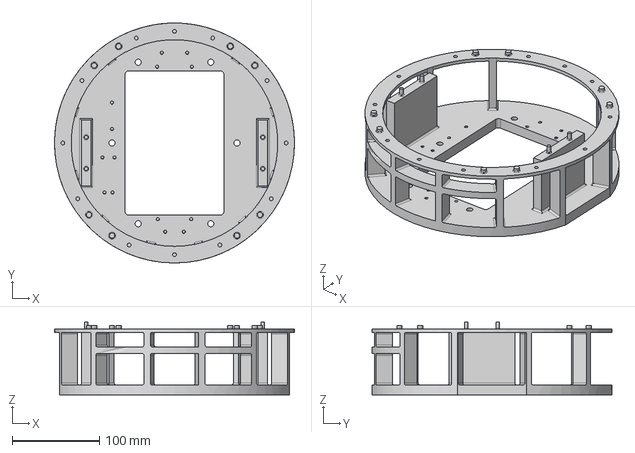
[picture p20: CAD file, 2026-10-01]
chassis/mechanical/cad-parts/R1-C4 - Chassis-part 1.step
274.3 x 274.3 x 83.4 mm

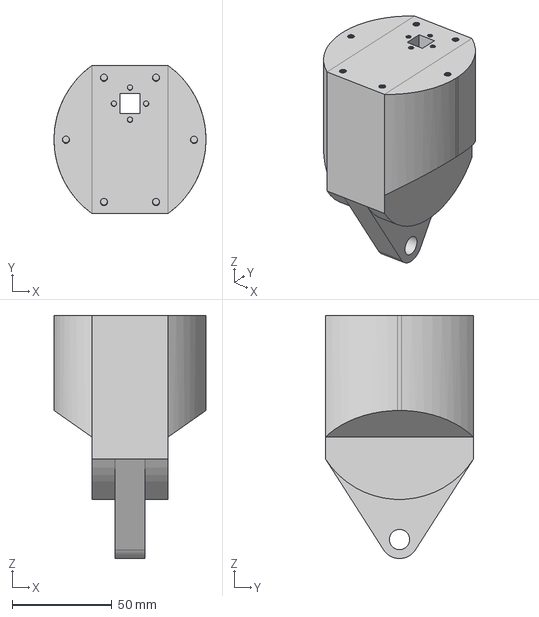
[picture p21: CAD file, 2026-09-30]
central-foot-lift/mechanical/cad-parts/R1-C4 - Ankle.step
76.2 x 74.3 x 121.8 mm

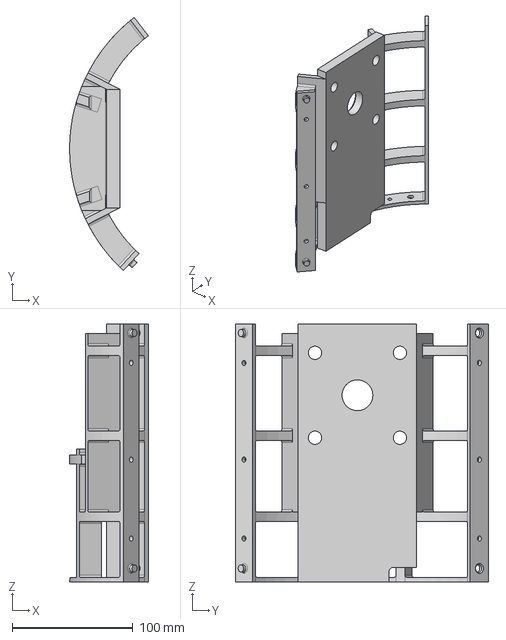
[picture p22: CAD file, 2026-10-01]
chassis/mechanical/cad-parts/R1-C4 - Chassis-part 5.step
65.2 x 209.8 x 213.8 mm

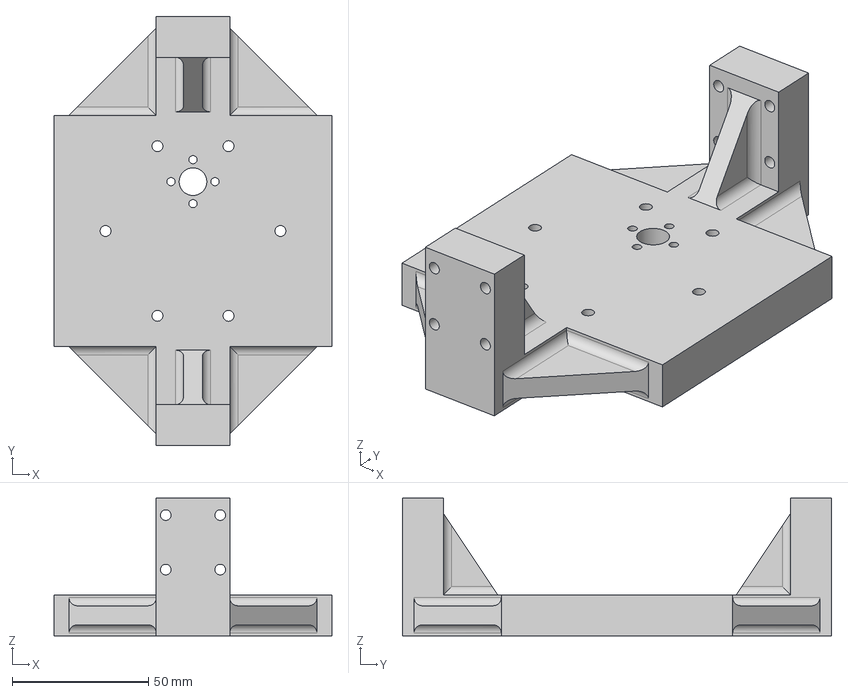
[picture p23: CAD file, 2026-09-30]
central-foot-lift/mechanical/cad-parts/R1-C4 - Central-foot-lift-carriage.step
102.0 x 157.5 x 50.5 mm

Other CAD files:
chassis/mechanical/cad-parts/R1-C4 - Chassis-part 4.step
central-foot-lift/mechanical/cad-parts/R1-C4 - Linear-motion-stop.step
central-foot-lift/mechanical/cad-parts/R1-C4 - Lift-motor-mounting-bracket.step

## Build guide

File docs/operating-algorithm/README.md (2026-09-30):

# Global Operating Algorithm

A global operating algorithm was developed during the first year of the R1-C4 project to define how the robot's main functions interact.

The objective was to establish a logical sequence for the robot's behaviour before implementing all of the autonomous functions.

## General Principle

The algorithm connects the main subsystems of R1-C4, including:

- User detection and facial recognition
- Head orientation and target tracking
- Robot movement
- 2-3-2 transformation
- Central-foot control
- Sensor and actuator management

The global architecture was designed to coordinate perception, decision-making and mechanical actions within the robot.

## Vision and Tracking

The vision system was designed to detect and recognise a user before tracking their movement.

The initial approach combined:

- LBPH facial recognition
- CSRT real-time tracking
- Kalman filtering for motion prediction

The Jetson Nano processes the visual information and sends correction commands to the ESP32, which controls the corresponding actuators.

## Role in the Project

Creating the operating algorithm helped define the interactions between the different subsystems before full integration.

It also provided a common reference for the mechanical, electronic and software development of R1-C4.

## Operating Flowchart

The global operating flowchart developed during the first year is shown below:

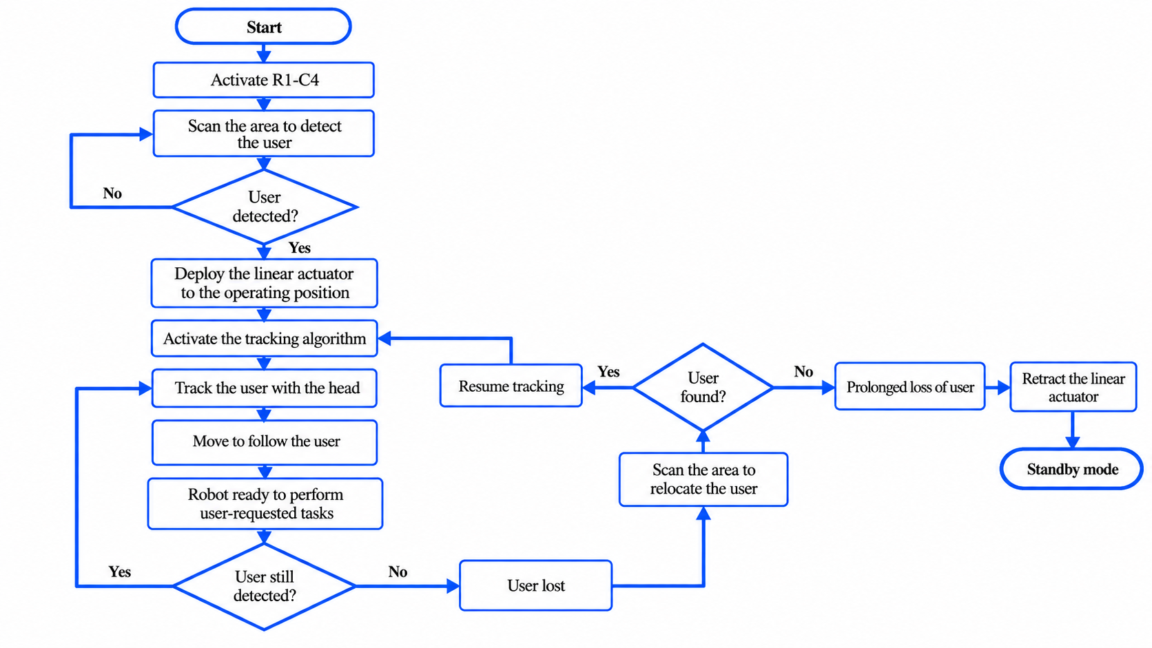
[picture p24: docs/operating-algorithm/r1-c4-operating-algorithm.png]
R1-C4 Global Operating Algorithm


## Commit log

2026-09-30 Initial R1-C4 project portfolio
    [R1-C4 - Ankle.step, R1-C4 - Central-foot-assembly-extended.step, R1-C4 - Central-foot-assembly-retracted.step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]
2026-10-01 Update R1-C4 project
    [R1-C4 - Central-foot-assembly-extended.step, R1-C4 - Central-foot-assembly-retracted.step, R1-C4 - Chassis-assembly.step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]
